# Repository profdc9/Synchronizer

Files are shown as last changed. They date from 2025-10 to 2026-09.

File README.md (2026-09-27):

# Synchronizer

Keep a mechanical pendulum clock on time by disciplining it to NTP or GPS —
**without modifying the clock in any way.**

The device sits behind the clock. Two coils reach through the back of the
case: one listens to the pendulum, the other nudges it. Nothing is glued to
the bob, nothing is drilled, nothing is tapped into the movement. Take the
device away and you have an ordinary pendulum clock again.

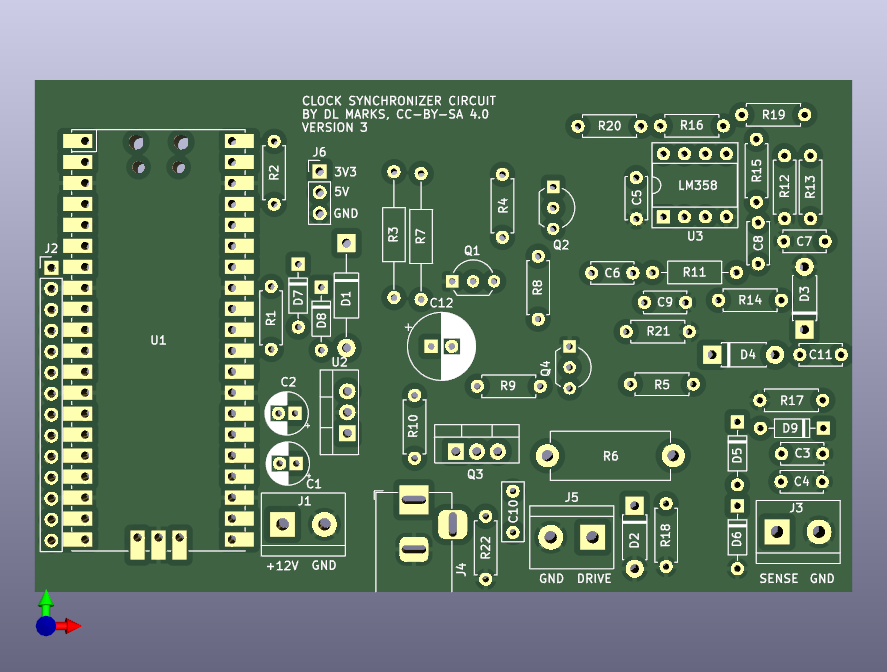
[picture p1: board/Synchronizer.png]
The board


## How it works

A pendulum clock keeps time by counting swings. If the pendulum runs a
little fast or slow — and they all do, with temperature, with the mainspring
unwinding, with the barometric pressure — the hands drift. The usual fix is
to adjust the rating nut and accept a few seconds a day.

This device measures the pendulum against an accurate reference and gives it
a very small push, at the right moment, to hold it on time.

### Sensing the pendulum

The **sense coil** is an air-cored coil of many turns. It sits behind the
case, near one end of the pendulum's travel, and forms a parallel resonant
tank with C3 (in parallel with C4, an optional trim position). The firmware
drives that tank at its resonant frequency with a square wave.

When the bob swings past, it changes the coil's inductance and loads it with
eddy-current loss. Either way the tank is pulled off resonance, its
impedance falls, and the voltage across it drops. An LM358 amplifies that,
and the result is read two ways: as the raw waveform, and through an
envelope detector that turns it into a slow bump. The bump is the bob going
past.

Arrival time is taken as the **midpoint between the two threshold
crossings**, not the peak. At the end of its travel the bob is nearly
stationary, so the bump is broad and its peak is poorly localised — but the
two flanks are steep and symmetric about the turning point.

### Nudging the pendulum

The **drive coil** is wound on a soft iron core and sits at the other end of
the swing. Energising it attracts the bob's steel backing. It can only pull,
never push, so correction is entirely a matter of *when*:

- pulse **just before** the bob arrives → it gets there sooner → **the clock
  advances**
- pulse **just after** it turns and starts back → it is held a moment
  longer → **the clock retards**

The pushes needed are tiny. On the development clock, correcting 11 s/day
works out to about **113 microseconds of retard per swing** — far too little
to deliver as a pulse every swing. So the firmware accumulates the demand
and spends it whole: one short pulse every few dozen swings.

### Keeping time

A Raspberry Pi Pico W runs the whole thing, and serves a web interface for
everything else — status, calibration, tuning. Setting one up needs no
serial terminal and no app: a board with no network raises its own access
point, and joining it opens the setup form. Afterwards it answers at
`synchronizer.local` and advertises itself over DNS-SD, so there is no IP
address to hunt for. The page carries a console that runs the same command
line as the serial port, and the same thing is reachable from `curl` for
scripting or remote debugging.

It gets the time over Wi-Fi by NTP, and keeps a model of UTC that NTP
corrects in both phase *and* rate —
the RP2040's crystal is only good to around 30 ppm, which is 2.6 s/day, a
sizeable fraction of the error being removed. A GPS receiver can be wired to
the expansion header later.

## The hardware

A single board, 99 × 62 mm, all through-hole parts. It is deliberately
**single-sided** — every track is on the bottom copper, with no vias and no
jumpers — so it can be milled at home if need be, though the boards in the
photo were commercially made.

### Connections

| | |
|---|---|
| **J1** | +12 V input, screw terminal |
| **J4** | +12 V input, barrel jack (wired in parallel with J1) |
| **J3** | Sense coil, screw terminal |
| **J5** | Drive coil, screw terminal |
| **J2** | 14-pin expansion header |

J2 carries GPIO5–GPIO15 with three grounds, for a GPS receiver or anything
else. GPIO12 and GPIO13 are UART0 TX/RX, on pins 10 and 11.

### Circuit blocks

**Power.** 12 V in, a 7805 down to 5 V, then a 1N5819 Schottky (D1) feeding
the Pico's VBUS and the LM358's supply. The diode is what lets you plug in
USB without back-feeding the regulator.

**Tank drive.** GPIO2 → Q1 (2N3904) → Q2 (2N3906), which injects into the
sense tank through R5 from the 12 V rail. A square wave at resonance.

**Amplifier.** Two inverting LM358 stages, both with 100 kΩ feedback,
biased to about 1.5 V so they run from a single supply. The op-amp is
socketed.

The first stage is fed from the tank through C6, only 100 pF, so its
reactance — roughly 80 kΩ at 20 kHz — dominates the 10 kΩ input resistor.
That makes the stage a gentle high-pass of about ×1.3 at 20 kHz rising with
frequency, rather than a flat ×10. C6 is a light tap on the tank rather than
a load on it, and it also adds its own 100 pF to the tank's capacitance
alongside C3. The second stage is AC-coupled through C8 and does run at
about ×10.

**Detectors.** The amplified waveform goes to ADC1 through R20. It also goes
through R19 and C11 into a clamp-and-rectify envelope detector (D3, D4) with
C9 and R21 setting the decay, and that goes to ADC0. D7 and D8 clamp both
ADC inputs to 3V3; D5, D6 and D9 clamp the tank input.

**Drive.** GPIO4 → Q4 (2N3904) → pulls the gate of Q3, an IRF9540N P-channel
MOSFET, whose source sits on +12 V. **GPIO4 high energises the coil.** The
current runs through R6, a 10 Ω power resistor. D2 (UF4007) is the flyback
clamp across the coil, and R22 with C10 snubs the switching node. R17 and
R18 are unpopulated positions for damping the coils if you need it.

**R6's job is damping the drive circuit's oscillations, not setting a
current limit by design** — size it to the coil actually wound rather than
assuming the populated value. A lower-resistance coil wants a smaller R6, and
in many cases R6 can be 0 Ω outright; a higher-resistance coil can tolerate,
and may need, more damping.

> **A word of caution about R6.** The coil's DC resistance depends on what
> you wind, and R6 is in series with it across 12 V. A pulse left on could
> put several watts into that resistor. The firmware bounds every pulse
> three independent ways — a hard ceiling on width, a watchdog timer that
> drops the pin regardless of what the rest of the code believes, and a
> token bucket capping the long-run duty cycle — and the pin is driven low
> before anything else initialises. Keep those limits in mind before
> widening the default pulse.

### Pin assignments

| Signal | Pico | Function |
|---|---|---|
| `/OSCIL` | GPIO2 | tank drive, square wave at resonance |
| `/PULSE` | GPIO4 | drive coil; **high = coil energised** |
| `/AMPLITUDE` | GPIO26 / ADC0 | envelope detector output |
| `/OSC_SIGNAL` | GPIO27 / ADC1 | amplified tank waveform |

## Physical setup

<table>
<tr>
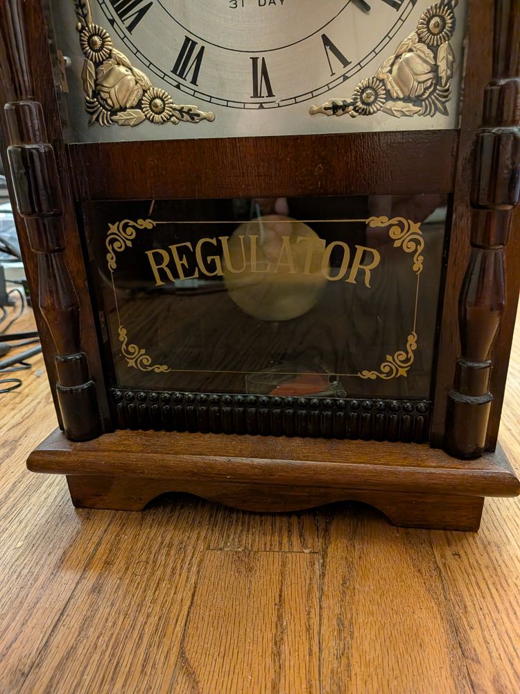
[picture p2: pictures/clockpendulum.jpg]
The development clock
<td width="50%"></td>
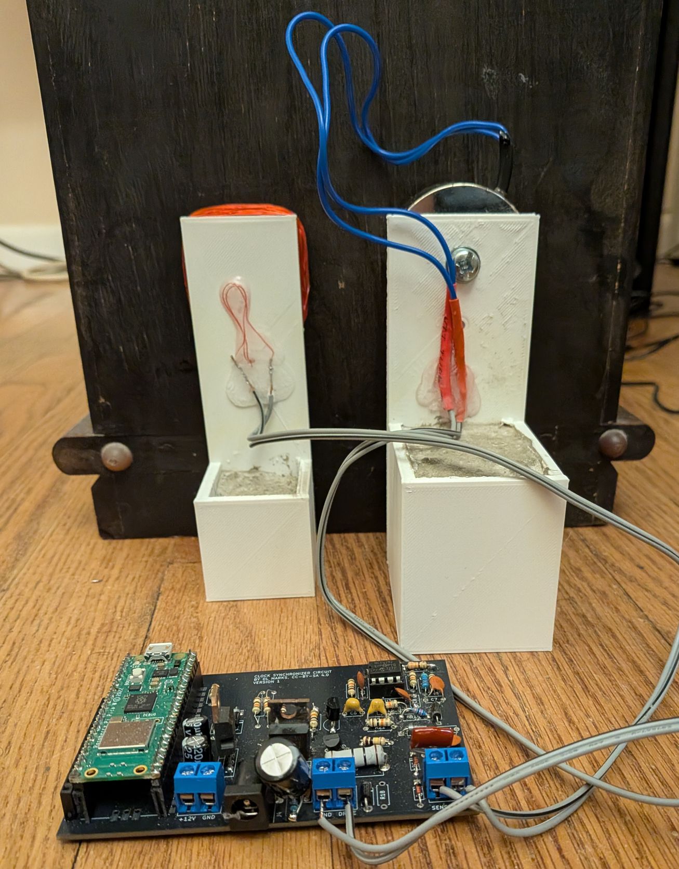
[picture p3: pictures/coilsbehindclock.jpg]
Both coil holders, wired to the board, standing behind the clock
<td width="50%"></td>
</tr>
<tr>
<td>The development clock — a 31-day mantel regulator. Neither coil touches
it; both stand free behind the case, reaching through the back wall.</td>
<td>The two coil holders assembled and wired to the board, placed at
opposite extremes of the pendulum's swing — the recommended default
geometry. Each stands on a 3D-printed platform with a ballast cup at its
base — filled here with cement — so it stays put on the shelf rather than
picking up the pendulum's own vibration.</td>
</tr>
<tr>
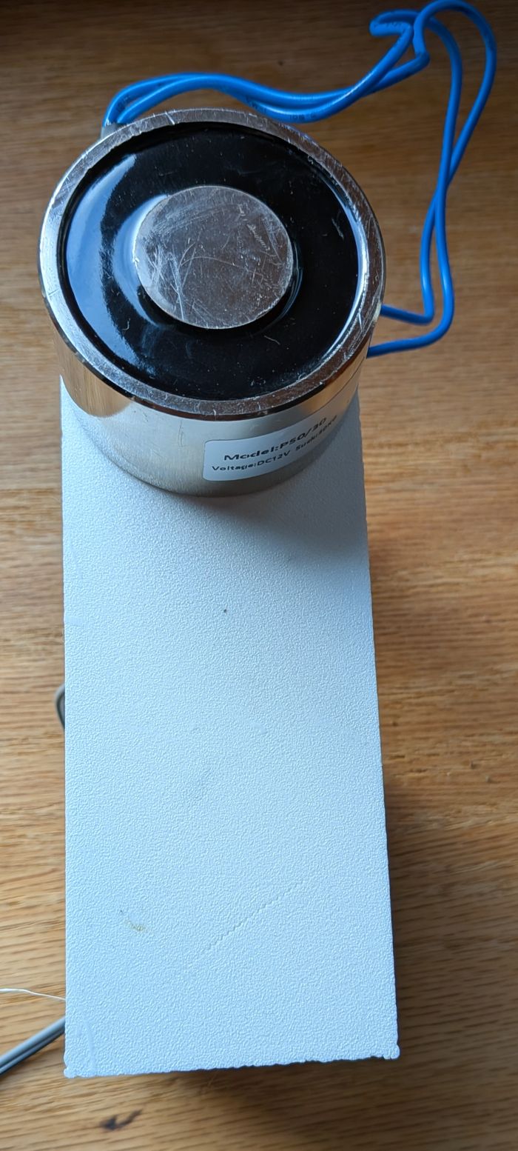
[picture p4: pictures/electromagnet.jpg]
The drive electromagnet on its mount
<td></td>
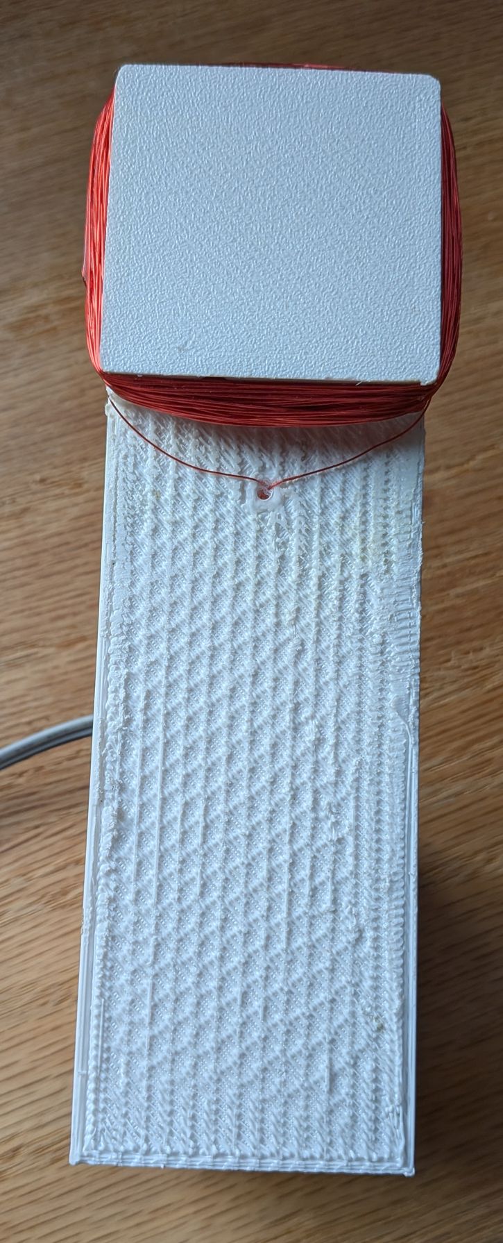
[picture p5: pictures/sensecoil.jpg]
The sense coil on its winding form
<td></td>
</tr>
<tr>
<td>The drive coil: a 50 mm × 35 mm, 500 N lifting electromagnet, 12 V at
about 250 mA, on its holder.</td>
<td>The sense coil, wound on its own form — the parallel resonant tank
described above.</td>
</tr>
</table>

Both holders are FreeCAD models, parametric in coil/magnet dimensions — see
`CAD/` below.

## The web interface

The device serves its own dashboard — no app, no cloud account, nothing to
install. These are from the clock above, running live.

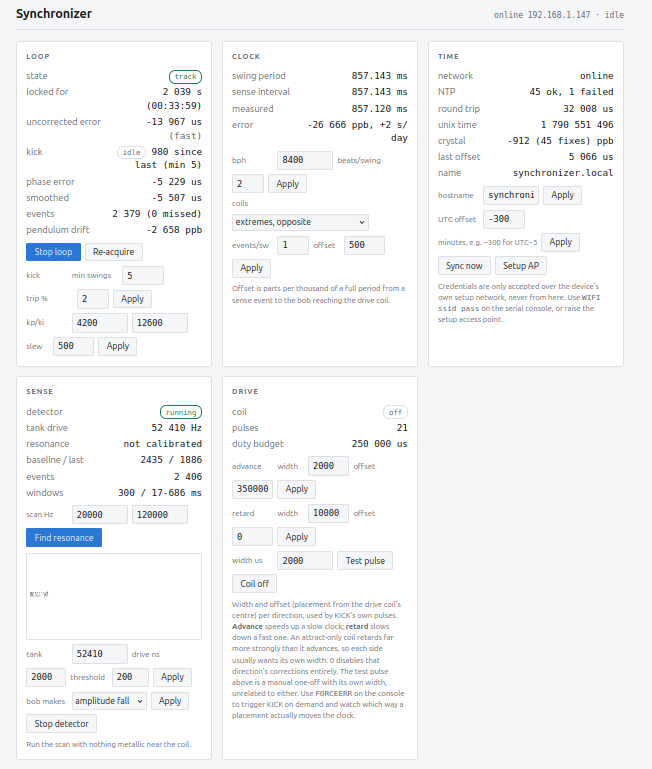
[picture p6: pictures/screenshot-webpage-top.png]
Loop, clock, time, sense and drive


At-a-glance status: the loop's lock state and uncorrected error, the clock's
measured swing rate, network and NTP health, the sense detector, and the
drive coil's per-direction pulse widths — all on one screen, live.

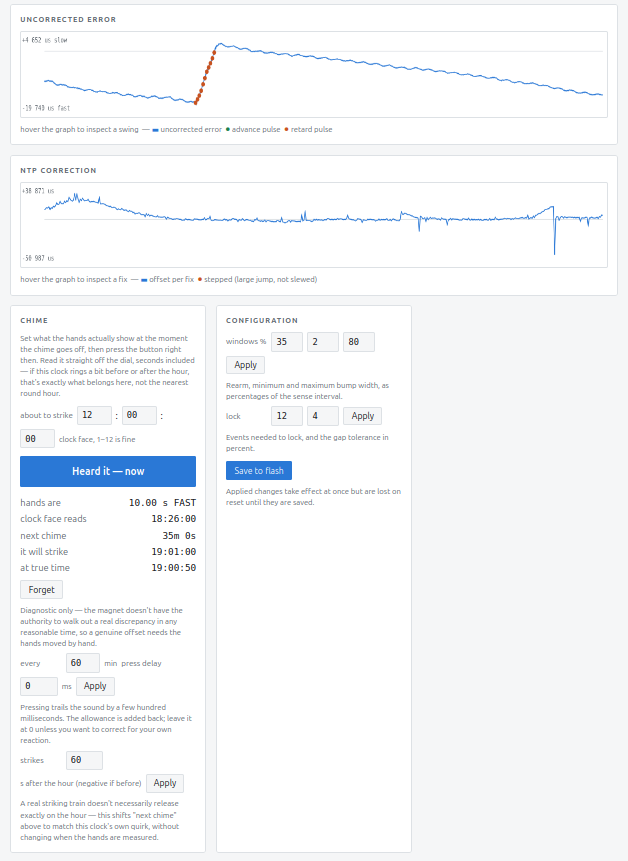
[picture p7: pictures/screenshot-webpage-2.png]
Error/correction history and the chime diagnostic


The uncorrected error over time, with advance and retard pulses marked where
they fired; the size of each NTP correction below it; and the chime
diagnostic showing what the hands should currently read.

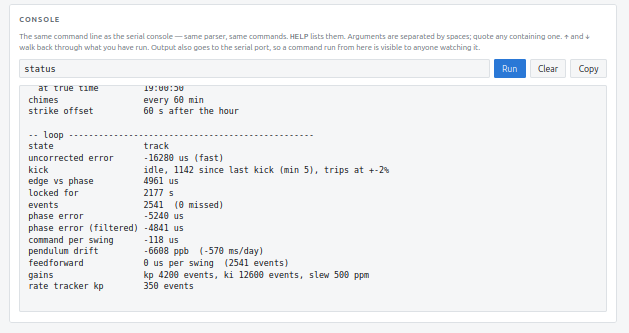
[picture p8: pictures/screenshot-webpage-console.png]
The console


The same command line as the serial port, in the browser — `STATUS` shown
here, but any command works, from `curl` or from this console.

## Repository layout

| | |
|---|---|
| `board/` | KiCad 7 project — schematic, PCB, gerbers, and a pcb2gcode setup for milling |
| `Code/synchronizer/` | Pico W firmware. See [its README](Code/synchronizer/README.md) for build and bring-up. |
| `CAD/` | FreeCAD models, parametric, plus their STLs. See [its README](CAD/README.md) for what each one is. |
| `Simulations/` | Qucs-S / ngspice models of the coil sensor and the coil pulser |

## Status

The board is built, the firmware runs the loop against the real clock shown
above, and it locks and holds it on time. Correction uses **KICK**: a
one-directional bang-bang scheme, no up-front gain measurement needed — it
fires a short pulse no more than once every few swings, only while the
error is on the side of zero that direction corrects, and stops once it
crosses back. An earlier design spent an accumulated phase error against a
measured "price per pulse" (`MEASURE`/`AUTH`); that path has been removed —
KICK needs no such calibration and has proven to be the simpler, working
approach.

Bring-up order, and the web interface, are in the
[firmware README](Code/synchronizer/README.md).

## Other clocks

Nothing in the firmware assumes a particular movement. Pendulum period,
escapement, gear ratio, coil placement and detector timing are all
configurable and stored in flash. The defaults describe the clock this was
developed against, and are only a starting point.

That clock is a 31-day wall clock about 40 cm tall. Measured from a
three-minute recording of its escapement:

- full swing period **0.857030 s** — nominally 6/7 s
- **8400 beats/hour**, 140 beats/min, **4200 full swings/hour**
- pendulum about **18.3 cm**
- runs roughly **11 s/day fast**
- **203 ms out of beat**, stably — the escapement releases at 0.678 of peak
  swing, where the bob still has 73% of its top speed, so it runs happily
  that way

Note that the bob only reaches each end of its travel once per full period,
so a coil at one extreme sees it 4200 times an hour, not 8400.

## Licence

The board carries **CC BY-SA 4.0** on its silkscreen, and the CAD models are
under the same licence; the full text is in
[`LICENSE-CC-BY-SA-4.0.txt`](LICENSE-CC-BY-SA-4.0.txt). The firmware sources
each carry a zlib-style permissive notice, and the full text is in
[`Code/synchronizer/LICENSE`](Code/synchronizer/LICENSE).

Daniel Marks

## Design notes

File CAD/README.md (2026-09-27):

# CAD

FreeCAD models for the coil and electromagnet holders, all designed by
Daniel Marks for this project. Each has a base cup for ballast (rocks, steel
shot, cement, ...) so the holder stands still on its own rather than picking
up the pendulum's vibration.

| File | Role |
|---|---|
| `WeightedCoilForm.FCStd` | The sense/drive coil holder, including the form the magnet wire is wound on. |
| `WeightedElectromagnetHolder.FCStd` | The platform that holds the drive electromagnet — in the photos, a 50 mm × 35 mm, 500 N lifting magnet, 12 V at about 250 mA. |
| `CoilBobbin.FCStd`, `CoilForm.FCStd`, `CoilFormWithPCBHolder.FCStd`, `CoilFormWithPCBHolder2.FCStd` | Earlier coil-form and PCB-holder designs. |

STLs are the printable exports of the corresponding model; `.FCBak` files are
FreeCAD's own backups and can be ignored.

## Licence

**CC BY-SA 4.0**, the same as the board — see
[`LICENSE-CC-BY-SA-4.0.txt`](../LICENSE-CC-BY-SA-4.0.txt) at the repository
root.

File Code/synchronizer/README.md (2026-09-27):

# Synchronizer firmware

Disciplines a pendulum clock to NTP time (GPS later), without modifying the
clock. Two coils sit behind the case on the pendulum's swing path, acting
through the back wall.

Nothing here assumes a particular movement. Pendulum period, escapement,
gear ratio, coil placement and detector timing are all configuration held in
flash. The defaults describe the 31-day clock it was developed against —
they are a starting point, not a specification.

Target: **Raspberry Pi Pico W**, SDK 2.x.

## Building

```sh
export PICO_SDK_PATH=/home/dmarks/pico/pico-sdk
cmake -S . -B build -G Ninja -DPICO_BOARD=pico_w -DCMAKE_BUILD_TYPE=RelWithDebInfo
ninja -C build
```

`build/synchronizer.uf2` is the image. The console is USB CDC at any baud
rate; the UART pins stay free for a GPS receiver on J2.

### Host tests

The part of the firmware most likely to be quietly wrong is the arithmetic
in `control.c`, and it is also the part hardest to check on the bench — a
swinging pendulum takes minutes per measurement and never repeats exactly.
So `test/` compiles `src/control.c` *unmodified* against stub headers and
feeds it synthetic swings with a known answer:

```sh
make -C test check
```

It checks that a persistently fast clock trips a retard and a persistently
slow one trips an advance, each releasing again once the pulses pull the
error back past zero; that a schedule slip forces a hold and the loop
reacquires afterward; and that a direction left at zero width trips but
never actually fires or releases. Run it after touching the loop; it takes
a second.

## What each piece does

| File | Role |
|---|---|
| `board.h` | Pin map, taken from the schematic. Nothing else hard-codes a pin. |
| `sense.c` | Drives the tank at resonance, samples the envelope at 1 kHz, and times each swing. |
| `drive.c` | Fires the impulse coil, with the safety limits described below. |
| `timebase.c` | A UTC model disciplined by NTP in both phase and rate. |
| `netclock.c` | WiFi association and the NTP client. |
| `control.c` | The phase-locked loop, and the sigma-delta that turns its demand into whole pulses. |
| `cli.c` | The serial command line. `HELP` lists everything. |
| `config.c` | Settings in the last flash sector, CRC-checked. |
| `tinycl.c` | Your command-line parser, reused unchanged. |

## Two things worth knowing before powering it up

**The drive coil can cook R6.** `GPIO4` high energises the coil from +12 V
through R6. Its job is damping the drive circuit's oscillations, not setting
a current limit by design, so its value has to be picked for the coil
actually wound: a lower-resistance coil wants a smaller R6, and in many
cases R6 can be 0 Ω outright, while a higher-resistance coil can tolerate,
and may need, more damping. Check the current schematic rather than
assuming a number here. Until the coil's DC resistance is measured and R6
sized for it, the current is unknown, and a stuck pulse could put several
watts into that resistor. So the firmware bounds every pulse three
independent ways: a ceiling of 100 ms on
any single pulse, a separate watchdog checked every 5 ms that forces the pin
low regardless of what the rest of the code believes, and a token bucket
that caps the long-run average duty at 2%. The pin is driven low
in `drive_init()` before anything else runs. Default pulse width is a timid
2 ms — widen it once you know what the coil draws.

**Nothing acts until you say so.** `control_enabled` defaults off, and even
once it is on, `PW`'s two widths gate whether either direction can ever
fire - 0 refuses that direction outright rather than falling back to a
guessed width. A fresh board will sit there sensing and telling you what it
sees; KICK needs no calibration step before it can act, just a nonzero
width for whichever direction(s) you want it to use.

## Bring-up, in order

**A firmware update can silently reset everything below.** The config sector
carries a magic number and a version; if a build changes the struct layout,
the device restores defaults on its next boot rather than reading a stale
layout — deliberately, since the alternative is misinterpreting bytes that
used to mean something else. That is the right call for tuning values, which
are guesses anyway, but it means `THRESH`, `WINDOWS`, `PW`, `PTIME`, `KICK`
and everything else below can vanish after a routine reflash with no warning
beyond `STATUS` quietly showing different numbers than you left it with. If a
clock that was working stops acquiring or measuring right after an update,
suspect this before suspecting the update's actual change — walk back through
the steps below rather than assuming the new code broke something.

**Run `RECREATE` before flashing new firmware.** It prints the sequence of
commands that would rebuild the current configuration from defaults —
`GEOMETRY`, `WINDOWS`, `PW`, `KICK`, and everything else that has been
tuned, `SAVE` included. It does not print `WIFI`; credentials are
deliberately left out of it. Save the output before a version bump wipes
it, and replaying it is a one-paste recovery instead of redoing bring-up
from scratch.

**0. Pick the tank components.** The inductive sense works best somewhere in
30-100 kHz. If you don't already know the sense coil's inductance, measure it
directly with an LCR meter, or estimate one you're winding yourself from
`L = mu_0 N^2 A / l` (turns squared, cross-sectional area, over coil length).
Either way, solve for C3 to land on a target frequency f in that band:

```
C = 1 / (4 pi^2 f^2 L)
```

A typical C3 lands somewhere between 1000 pF and 10000 pF for coils in the
few-mH range tuned into 30-100 kHz — worth a sanity check against the
calculation before ordering parts; a result far outside that band usually
means the wrong L or the wrong target frequency, not an unusual coil.

C3 is not the only capacitance across the tank, though: C6 taps the tank to
feed the amplifier — lightly enough that it does not load it down — but it
still adds its own value in parallel with C3, currently 30 pF on the
development board, so account for it (`C3 + C6`) when solving for a target
frequency, not C3 alone.

Pick the nearest standard capacitor value - an exact match is not needed,
because the next step measures the tank's *actual* resonance rather than
trusting the calculation. The development board's own sense coil is 2.5 mH on
a square 25x25 mm form, for reference.

**Use a film capacitor for C3, or a ceramic NP0/C0G type - not a typical
X7R.** X7R's capacitance shifts substantially with temperature and applied
voltage, which is exactly what a frequency-determining tank component cannot
tolerate; the tank frequency will drift and the whole detector chain rides on
that frequency staying put.

**1. Calibrate the tank.** With the sense coil on J3 and **nothing metallic
near it** — not the bob, not your hand, not a steel rule on the bench:

```
RESONANCE 20000 120000 Y
```

Two passes. A coarse scan locates the peak and gauges its width, then a fine
scan covers about three linewidths centred on it. The peak frequency comes
from a parabolic fit to the three points around the fine maximum, so it is
not limited to the step size; the half-power points come from linear
interpolation across the fine scan. The trailing `Y` prints the curve as a
bar chart.

It reports the peak, the −3 dB points, Q, and the two steepest flanks, then
adopts the peak. `SAVE` keeps it.

On a synthetic resonance the peak comes back within a few hertz — well under
one scan step — for Q anywhere from 12 to 120 and across the whole band. Q
itself is good to about 1% at moderate Q and drifts low by roughly 10% on a
very sharp tank, where the fine scan's step size limits how precisely the
flanks can be located.

Two things to watch for, both of which the command warns about:

- **Clipping.** If the envelope rails, the peak goes flat, the parabola
  slides off it and Q collapses. On the synthetic test a railed scan came
  back 302 Hz out with Q wrong by half. The command refuses to adopt a
  clipped result and leaves the drive where it was.
- **Harmonics.** The drive is a square wave, so a scan that passes through
  f0/3 and f0/5 will show smaller responses there too. The fundamental
  always wins, but do not be surprised by the subpeaks in the plot.

**Should you sit exactly on the peak?** Not necessarily. At the peak the
amplitude is stationary, so pure detuning by the bob only moves it to
*second* order. On the steepest flank — about 0.354 bandwidths either side of
centre, which is what the command prints — detuning moves it to first order,
which can be far more sensitive. Against that, the bob also *loads* the tank
through eddy-current loss, and that lowers the peak to first order even at
centre. Which mechanism dominates depends on your coil, your frequency and
how much brass versus steel the bob presents, so it is worth trying both:
run `RESONANCE`, note the peak amplitude, then hold the bob at its closest
approach and read `STATUS` at the peak and at each flank. Take whichever
gives the biggest swing.

`SWEEP 5000 60000 250` still prints a raw table if you want to look at the
whole band by hand, and `CAPTURE 500000 512` dumps the amplified waveform
from ADC1 so you can see what the LM358 is actually producing.

**2. Place the coil.** The tank peak found in step 1 is *not* where the
detector should sit. The bob's eddy losses drag the loaded resonance
downward, so the drive wants to be below the unloaded peak — on the
development clock, about 270 Hz below, worth 20% more signal. That optimum
moves whenever the coil moves, so let the board find it:

```
MODSCAN 0 0 0
```

It sweeps the drive, watches each frequency for longer than a full swing,
and reports how far the bob moves the envelope. **The peak-to-peak figure is
the entire signal budget** — maximise it by moving the coil, re-running after
each move. It leaves the drive on the winner.

**The recommended default geometry is opposite extremes**, and it is worth
starting there rather than exploring alternatives: sense coil at one extreme,
drive coil at the other. The photos in the top-level
[README](../../README.md#physical-setup) show the two coils placed exactly
this way. Place each coil about a quarter of the bob's own
diameter *beyond* where the bob's metal actually reaches at that extreme —
not centred on the point of deepest penetration. At the true turning point
the bob is nearly stationary, which is what produces a wide, poorly-localised
dip; offsetting the coil means it only sees the bob while it is still moving,
which gives a narrower, more sharply-timed crossing for the sense coil, and
lets the drive coil work through its *lateral fringe field* rather than a
direct, on-axis pull. "Bob diameter" here means the extent of the metal, not
any outer decorative dimension — the development clock's bob is a steel core
inside a brass envelope, so it is the full brass-covered diameter that
matters, since eddy-current sensing responds to any conductor and the brass
alone would still register even though it is not itself magnetic.

The drive coil benefits in particular from a design that leans into the
fringe field rather than fighting it: a commercial electromagnet meant for
attaching to metal, with a steel bolt glued to its own centre core so the
field extends past the coil's physical edge, measurably outperformed direct
placement attempts on the development clock — an evening of no measurable
authority at all became a clearly significant one purely from this change,
nothing else. Start here rather than rediscovering it by trial and error.

Geometry matters more than fine positioning. The bob's distance from a coil
at the swing *extreme* varies by twice the amplitude; at the *centre of
travel*, only by one amplitude. On the development clock that was 206 counts
against 75 — nearly 3:1 in favour of the extreme. Against that, the centre
gives two passes per period and the bob is moving fastest there. Try both;
`TRACE` tells you which you have, since a coil at the centre shows two
cycles per period and one at an extreme shows one.

Coil diameter is a genuine compromise: sensing depth grows with coil radius,
so too small cannot reach, while spatial resolution is also set by diameter,
so too large smears the pass into a slow sinusoid. Comparable to the standoff
is a good rule. Note that if the coil, the standoff and the bob's total
travel are all of similar size — 25 mm each on the development clock — the
bob never leaves the coil's field and the envelope is a smooth sinusoid at
the swing frequency rather than a sharp pass. That is geometry, not
misplacement, and it times perfectly well.

**3. Set the threshold.** `THRESH` is in ADC counts of envelope excursion
away from the tracked baseline, in the direction `DIR` selects. It decides
three things at once, which is why the extremes are both bad:

* whether a swing triggers at all,
* how wide the event is — a low threshold means crossing near the top of the
  dip and staying below it for most of the period,
* and the timing precision, since both edges are timed at exactly this level
  and precision is noise divided by the slope where they cross.

Run `WATCH Y` and look at the printed `peak`, which is the excursion the bob
actually produces. **Half of it is about right.** On the development clock,
peak ≈ 160 counts:

```
 THRESH  events  gap median   gap sd   width   misses
     25      17     857.3 ms     2.68   477 ms        2
     50      19     858.3        5.19   447          0
     90      19     856.6        2.24   324          0
    110      19     857.4        2.53   247          0
```

At 25 the events ran 477 ms wide against the 514 ms `max_event_pct` limit,
so one swing in ten was abandoned as stuck-high. At 90 — 56% of peak — no
misses and the lowest jitter. Too high is bad too: near the dip's floor the
slope flattens again and normal amplitude variation starts causing misses.

**If it stops acquiring entirely — not one swing in ten, every one of
them — the loop can look dead while the signal underneath is perfectly
healthy.** `STATUS` still shows `events` frozen at whatever it was, `chatter`
climbing steadily, and `baseline`/`last sample` both clearly alive and
moving. That combination — chatter increasing, `events` not — means events
are opening and never closing: every single one is running past
`max_event_pct` and getting abandoned as stuck-high before it can complete,
so none of them ever reach the width gate to be counted, rejected, or even
logged by `WATCH` (its echo only fires on events `sense.c` actually reports).
This is the same failure as the table above, just at 100% instead of 10% —
most often seen right after a reflash wiped `WINDOWS` back to its defaults
while the coil geometry underneath had since changed enough that the old
percentages no longer fit.

Diagnose it with `TRACE`, not by guessing new `WINDOWS` numbers: it plots the
raw envelope against time, bypassing the threshold/event state machine
entirely, so it shows the true dip regardless of whether detection is
currently working at all. Read the actual event width and gap straight off
the printed trace — where the excursion crosses `THRESH` on the way in to
where it recrosses `THRESH` minus `HYST` on the way out is the width; from
that crossing to the next event's crossing is the gap — and set:

```
WINDOWS <rearm%> <min%> <max%>
```

so `max%` clears the real width with margin and `rearm%` sits comfortably
*under* the real gap, not just under the nominal interval. A width that now
runs 60-70% of the period rather than the ~30-40% the defaults assume is not
a sign of a broken swing; it is what the recommended opposite-extremes-plus-
offset geometry in step 2 produces once the coil is close enough to have real
authority, and `WINDOWS` exists precisely so this is a one-line fix rather
than a rebuild.

`HYST` sets how far *below* the threshold the excursion must fall before the
event is declared over. It costs nothing in timing — both edges are still
timed at `THRESH` — and it stops ripple near the threshold from ending an
event early, which the width gate would then throw away entirely. 30% is a
good default; `STATUS` counts how often it saves a swing.

**A warning about the diagnostics.** `ENV`, `TRACE` and `MODSCAN` take the
ADC away from the detector while they run, so the detector is blind for
their duration and the loop will miss those swings. That is fine when you
are setting up, but do not leave one running and expect the loop to hold
lock, and do not trust `measured interval` until they have aged out.

**4. Get time.** 

```
WIFI myssid mypassword
SAVE
```

Credentials live in flash, not in the source. `STATUS` shows the association
and the NTP fix count. The timebase needs a few minutes and at least two
fixes before it starts correcting the RP2040 crystal's own error, which is
around 30 ppm — 2.6 s/day, a quarter of what we are trying to remove.

**5. Let the loop lock without acting.**

```
PW 0 0
CONTROL Y
```

With both pulse widths zero the loop tracks but never fires — KICK still
updates its active/idle state and `STATUS`'s `uncorrected error`, it just
never reaches `fire_for()`. Let it sit and watch `uncorrected error` walk at
the clock's natural rate — about 11 s/day fast, from the audio measurement —
before turning either direction on.

**6. Place the drive pulse.** `GEOMETRY events_per_swing drive_offset_ppt`
sets how long after a sense event the bob reaches the drive coil, as parts
per thousand of a full period - 500 for opposite extremes, the recommended
default. Treat that as a starting guess, not a fact: get a rough number by
timing the onboard LED (it blinks once per sense event) against the drive
coil by eye or stopwatch, convert to ppt, and set it with `GEOMETRY`.

`PTIME advance_us retard_us` nudges the placement by hand if that
rough centre needs adjusting. Both parameters are the same signed offset
from that centre - a given number means the same physical instant whether it
is stored as the advance placement or the retard one. What matters here is
the *sign*: a pulse fired on the wrong side of the bob's turning point
advances when it should retard, or the reverse - not the exact instant
within the half-period, since KICK's hysteresis works with whatever
authority a reasonably-placed pulse actually has, rather than needing that
authority measured in advance.

**Anything that physically disturbs the pendulum invalidates the rate
tracker**, not just the count of swings it has seen — touching the coil,
running `COILTEST`, adjusting the drive placement by hand. A disturbance
leaves a contaminated `rate_q` that only washes out over roughly `2 * RATEKP`
swings on its own; reissuing the same `RATEKP` value forces a clean restart
instead of waiting it out, and is worth doing on reflex after any physical
change.

**7. Turn a direction on and watch it run.**

```
PW 2000 2000
KICK 5 25
CONTROL Y
```

`PW advance_us retard_us` sets how wide each pulse is; 0 disables that
direction outright rather than falling back to a guessed width - a
direction the coil cannot usefully drive should simply not fire. `KICK
min_swings threshold_pct` sets how many swings must pass between pulses,
and how far past zero - as a percentage of one swing period - the
uncorrected error has to go before a direction is judged to need
correcting; it releases again as soon as the error crosses back past zero,
not out to the opposite threshold. There is no separate advance-mode or
retard-mode to pick - KICK reacts to whichever side the error is actually
on, and can run both directions at once if both widths are nonzero.

There is no bench measurement left to run first, and nothing to `SAVE` a
number from - watch it over real time instead. `STATUS`'s `uncorrected
error` should walk toward the threshold, trip a `kick`, and walk back
toward zero over the next few pulses; `locked for` counts how long that has
been happening without an interruption. `FORCEERR <us>` can confirm KICK
trips and releases in the right direction on demand, but it cannot hold an
artificial error in place long enough to judge a pulse width by - the real
measurement against NTP overwrites it within about one swing (see the doc
comment above `forceerr_cmd` in `cli.c`).

Leaving one width at zero is legitimate: the loop then corrects in one
direction only, which is all a clock that consistently gains (or
consistently loses) ever needs.

**A sensor artifact worth knowing about, if a bench-measurement tool is
ever rebuilt.** An earlier version of this loop *did* measure how many
nanoseconds of phase one pulse was worth, by firing pulses for a fixed
run and fitting the phase shift against the pendulum's own rate tracker.
That measurement turned up a real trap, and the trap outlives the tool
that found it:

A placement sweep that comes back with a smooth, coherent
placement-vs-kick curve - one sign across half the range, the other sign
across the rest, exactly the shape a real coil authority curve should
have - is not on its own evidence that the coil is doing anything. Run
the same sweep with the magnet moved away from the clock entirely; if a
similar curve still comes back, none of it is mechanical.

The suspected cause was that firing the drive coil disturbs `sense.c`'s
demod directly (supply sag, ground bounce, or coupling straight into the
tank coil), and since that demod is a delay-and-multiply phase detector
built on an I/Q accumulator that runs every ADC tick and is never reset, a
glitch on even a few samples shows up as a step that decays only over the
accumulator's own multi-swing time constant - indistinguishable from a
genuine kick. The fix tried was a guard window (`SENSEDEAD <us>`) that
stopped feeding samples into the accumulator for that long on either side
of every pulse.

It backfired. Measuring the same sweep at three guard widths -

```
SENSEDEAD 30000    ->  best-magnitude points around +-25000 ns/pulse
SENSEDEAD 10000    ->  the same shape, roughly a third the size
SENSEDEAD 0        ->  every point within about 1 sigma of zero, no shape at all
```

- showed the "fix" was the dominant source of the curve, scaling with the
guard width rather than shrinking it. The reason is structural, not specific
to this hardware: `dm_I`/`dm_Q` is a single-bin correlator estimating the
Fourier coefficient of the envelope at one cycle per swing, and removing a
fixed window from that correlation sum every cycle does not just lower its
gain — the product of two sinusoids splits into a DC term and a
second-harmonic term, and the second-harmonic part integrated over just the
missing window does not cancel. Its phase depends on *where* the window
sits, not on the true phase being measured, so blanking manufactures a bias
that tracks pulse placement directly — worse for a sharp, non-sinusoidal dip
(real harmonic content to feed the bias) than for a clean sinusoid, and
worse the wider the guard window. `SENSEDEAD` was removed rather than
defaulted to 0 and left in the config, since a knob whose only well-tested
setting is "off" is a trap for the next person tuning this board.

With no blanking, the magnet-away curve did not clearly survive above noise
either. So whatever the original electrical effect is, if it exists at all
it is smaller than that measurement could resolve, and it was very unlikely
to matter next to a much bigger problem: an attract-only coil at a
fringe-field placement measured *microseconds* of authority per pulse
against a clock that needs *~100 microseconds per swing* to correct - over
an order of magnitude short regardless of how cleanly it was measured. KICK
sidesteps the whole question by never needing that number in the first
place; this is preserved for whoever next builds a tool that does.

## The web interface

Once the board associates, it serves a page on port 80 at the address
`STATUS` prints. Everything the serial console does is there: live status,
the clock and coil geometry, the detector, the drive coil, the loop, and a
resonance scan that draws its own curve.

The serial CLI keeps working alongside it — and is also *on* the page: the
Console card runs the same command line, through the same parser and the
same command table. There is no second syntax to keep in step.

```sh
curl -s -X POST 'http://synchronizer.local/api/cli?cmd=STATUS'   # queue it
curl -s        'http://synchronizer.local/api/cli'               # read the output
```

The output comes back as plain text, so this is as pleasant from `curl` or a
script as it is from the browser. It works because the SDK's stdio layer
fans every `printf` out to all registered drivers: a capture driver sits
alongside USB and is switched on around the command, so **not one of the
firmware's `printf` calls had to change**. Output still reaches the serial
port at the same time, so a command run from a browser is visible to anyone
watching the wire.

Three things to know:

- **A command runs from the main loop, never in the HTTP handler.** The POST
  queues it and returns `202`; the page notices the result counter change in
  `/api/status` and fetches the output. `RESONANCE` alone blocks for three
  seconds, which an HTTP handler must not do.
- **Output is capped at about 4 kB** and marked `[output truncated]` past
  that. `CAPTURE 500000 256` and a full `SWEEP` both fit; larger dumps want
  the serial console.
- **`WIFI` and `APKEY` are refused here.** Credentials are deliberately
  settable only over the setup access point, and letting the console set
  them from your LAN would quietly undo that. They still work on the serial
  console.

The USB and web consoles share one `tinycl` command buffer, so typing on the
serial port at the exact moment a web command runs can garble one of them.
The result is a rejected command, not a wrong one.

Two things shape the design:

- **A resonance scan blocks for about three seconds**, which an HTTP handler
  must not do. Requesting one only queues it; `web_poll()` runs it from the
  main loop and the page watches the `job` field until it clears, then
  fetches the curve. The same applies to writing flash.
- **`http_dispatch()` runs in lwIP callback context**, so it never
  allocates, never touches the ADC or flash, and never blocks. Each of the
  three connection slots owns its own request and response buffers.

The page lives in flash as a C string. **Edit `web/page.html`, not
`src/webpage.c`**, and regenerate:

```sh
python3 web/genpage.py          # rewrite src/webpage.c
python3 web/genpage.py --check  # fail if it is stale
```

The generator refuses to write unless it can parse its own output back into
the exact bytes of the source, so a mistake in the escaping cannot reach the
firmware silently.

**There is no authentication.** Anyone who can reach the device on your
network can energise the drive coil. The pulse ceiling, the watchdog and the
duty bucket in `drive.c` bound what that can do to the hardware, but they
are not a security boundary — put this on a network you trust, or keep it to
the serial console.

## First-time setup, with no serial terminal

A board that has never been told a network raises **its own access point**
instead, and so does one that has failed to connect three times running —
which is what a mistyped password looks like from the inside. There is no
way to get locked out.

1. Join the Wi-Fi network **`Synchronizer-XXXX`** (the last two bytes of the
   board's unique ID). The key is **`synchronizer`**, changeable with
   `APKEY`.
2. Open any page. The device runs a DHCP server so your phone gets an
   address, and answers every DNS lookup with its own, so the captive-portal
   check fails and the setup form opens by itself. If it does not, go to
   **192.168.4.1**.
3. Pick your network from the list, or type it — scanning is best effort
   while the AP is up, so an empty list is normal and the text field always
   works.
4. Press Connect. Credentials are saved to flash, the AP drops and the
   device joins your network, where it answers at
   **http://synchronizer.local**.

`AP Y` raises the access point by hand, `AP N` drops it, and the main page
has a button for it too.

### Finding it afterwards

An mDNS responder answers for **`<hostname>.local`** — `synchronizer.local`
by default, changed with `HOSTNAME` or from the page — and advertises the
web interface as an **`_http._tcp`** service, so it also shows up in service
browsers (`avahi-browse -rt _http._tcp`, Safari's Bonjour list, Android's
NSD) without anyone knowing an address. It runs on the setup access point
too, so even provisioning works by name.

This is a convenience, not a guarantee. `.local` resolves reliably on macOS,
iOS, Windows 10 and later, and Linux with Avahi; **typing it into a browser
on Android is unreliable**, though service discovery from an app works
there. `STATUS` always prints the plain address, and so does your router's
client list.

Anything typed as a hostname is reduced to a legal DNS label — lower-cased,
with everything but letters, digits and interior hyphens dropped. The name
it settled on is echoed back, so `Papa's clock` becoming `papasclock` is
visible rather than silent.

### A note on ordering

Provisioning and raising or dropping the access point are **deferred to the
main loop**, not done in the HTTP handler that asked for them. Saving
credentials writes flash with interrupts masked, and tearing down an
interface from inside an lwIP callback would take away the very network the
reply still has to travel over. So the handler records the request, answers
the browser, and the change happens a moment later.

**Credentials are only accepted over that access point.** `net_provision()`
refuses otherwise, so nobody on your LAN can repoint the device at their own
network — they would have to be in radio range and raise the AP first.

The key on the setup AP is not much of a secret; it is written above. Its
job is to stop your home Wi-Fi password crossing an open link in the clear
while you type it in. Anyone within radio range who knows the default could
provision an unconfigured board, so change it with `APKEY` if that matters
where the clock lives.

## Setting it up for a different clock

Six commands cover everything clock-specific. Each one takes effect
immediately and `SAVE` keeps it; the config carries a magic number and a
version, so changing the structure in a future build restores defaults
rather than reading a stale layout.

```
BPH      8400 2     beats per hour, and beats per full swing
GEOMETRY 1 500      sense events per swing, drive coil offset
WINDOWS  35 2 60    detector windows, as % of the event interval
LOCK     12 4       events needed to lock, gap tolerance %
SAMPLE   1000       envelope sampling rate
TANK     55000      tank drive frequency (RESONANCE finds this)
```

**`BPH`** is the gear ratio. `beats_per_swing` is 2 for an anchor, deadbeat
or pin-pallet escapement — two pallets, one tooth released per half period.

**`GEOMETRY`** is where you put the coils, and it is the one most likely to
differ from this build:

| Sense coil | Drive coil | Command |
|---|---|---|
| at a swing extreme | at the other extreme | `GEOMETRY 1 500` |
| at a swing extreme | at the same extreme | `GEOMETRY 1 0` |
| at the swing centre | at an extreme | `GEOMETRY 2 250` |

A coil at an extreme sees the bob once per full period; one at the centre
sees it twice. The offset is how long after a sense event the bob reaches
the *drive* coil, in parts per thousand of a full period.

**`WINDOWS`** are percentages of the expected interval between sense events,
not fixed microseconds, so they follow the pendulum. On a 0.857 s clock the
defaults resolve to a 300 ms rearm and a bump between 17 ms and 514 ms; on a
seconds pendulum, to 700 ms and 40 ms–1.2 s. `STATUS` shows the resolved
values.

The event schedule is exact integer arithmetic in all of these. Checked on
the host across 8400/3600/7200/5400/14400/9000 bph, one and two events per
period, and a single-beat escapement: **zero nanoseconds of error over a
year** in every case.

## The clock this was developed against

Measured from a three-minute recording of the escapement on 2026-09-10:

- full swing period **0.857030 s**, nominal 6/7 s
- **8400 bph**, 140 beats/min, **4200 full swings/hour, 100,800/day**
- pendulum about **18.3 cm**
- runs **~11 s/day fast**
- **203 ms out of beat** — stable, and mechanically fine; the escapement
  releases at 0.678 of peak swing where the bob still has 73% of its top
  speed. Curable by shimming the case if you want, but the project does not
  need it.

100,800 swings/day is the gear-ratio constant, so the clock-face calibration
is now a confirmation step rather than a prerequisite. `BPH` changes it if
this movement turns out not to be standard.

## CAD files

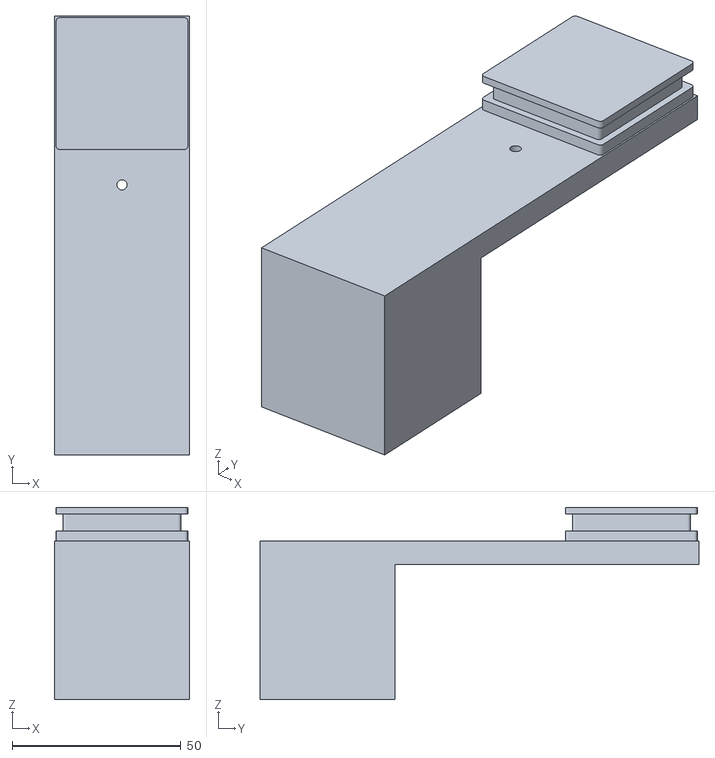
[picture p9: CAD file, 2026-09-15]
CAD/CoilFormStand-CoilFormTotal.stl
40.0 x 130.0 x 57.0

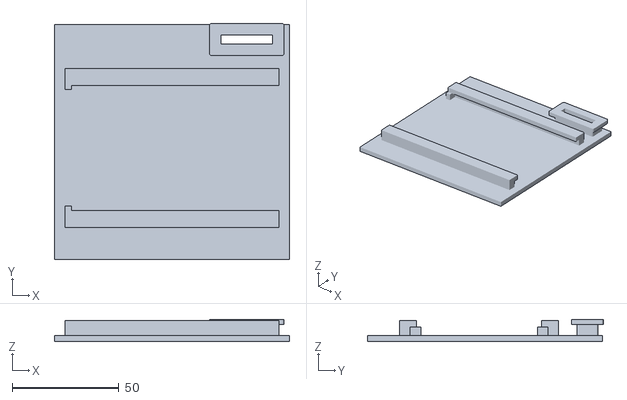
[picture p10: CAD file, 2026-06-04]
CAD/CoilFormWithPCBHolder-CoilFormTotal.stl
110.0 x 110.5 x 10.5

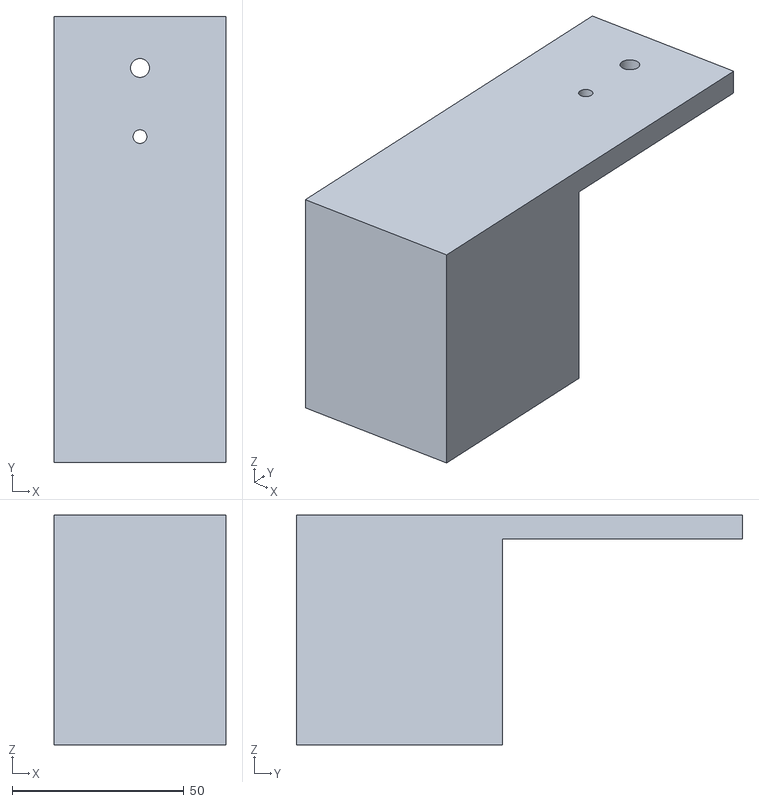
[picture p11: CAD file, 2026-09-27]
CAD/WeightedElectromagnetHolder-Electromagnet-Platform.stl
50.0 x 130.0 x 67.0

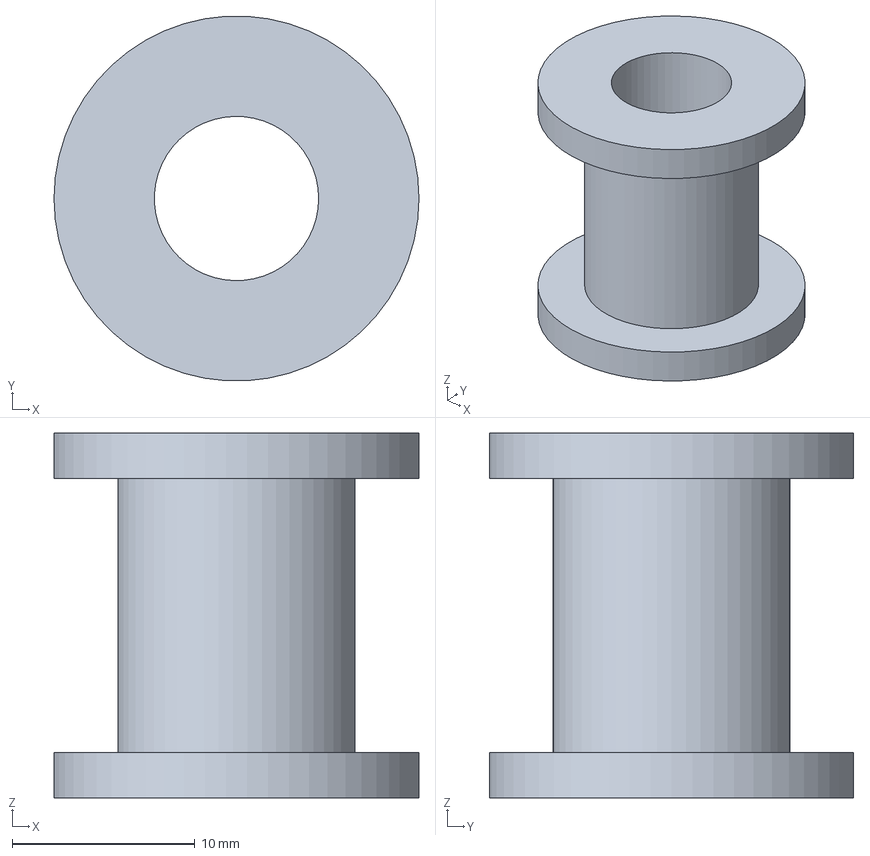
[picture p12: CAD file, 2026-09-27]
CAD/CoilBobbin.FCStd
20.0 x 20.0 x 20.0 mm

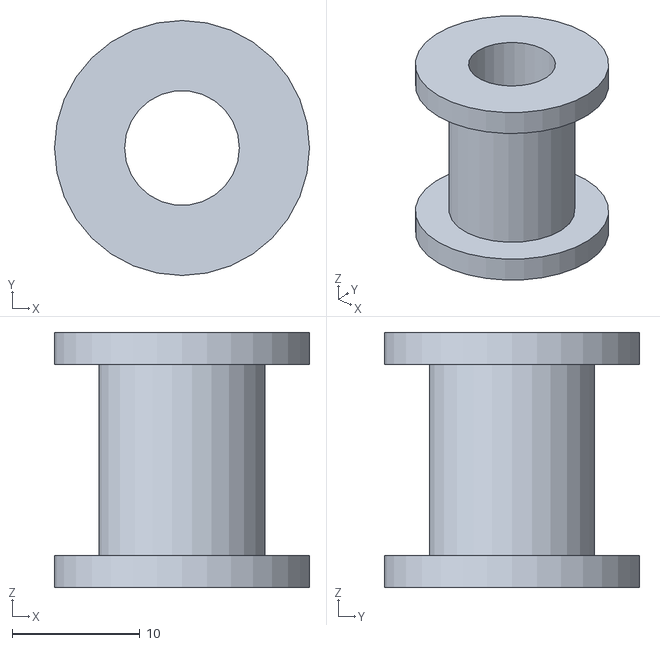
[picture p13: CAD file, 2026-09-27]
CAD/CoilBobbin-CoilBobbin.stl
20.0 x 20.0 x 20.0

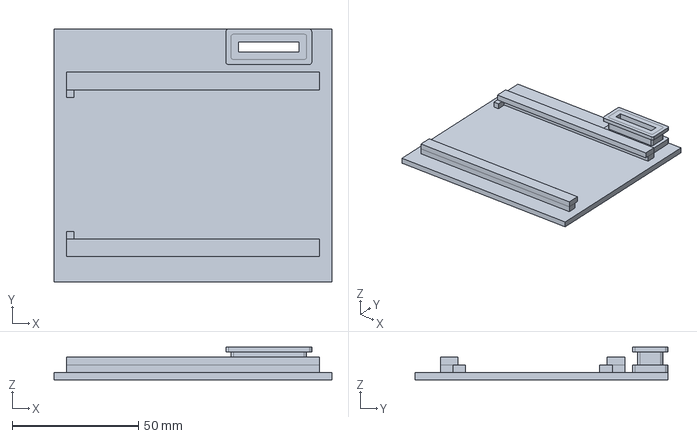
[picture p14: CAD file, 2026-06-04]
CAD/CoilFormWithPCBHolder.FCStd
110.0 x 100.0 x 13.0 mm

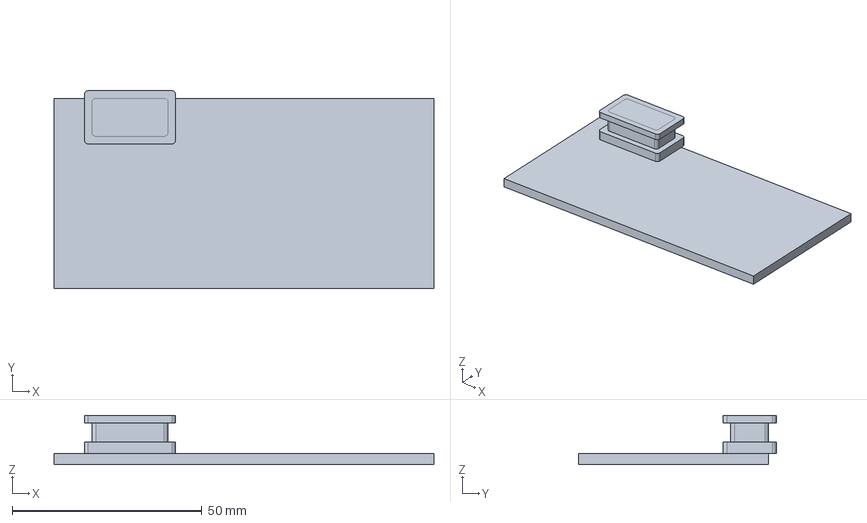
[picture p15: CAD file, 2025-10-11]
CAD/CoilForm.FCStd
100.0 x 52.0 x 13.0 mm

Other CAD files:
CAD/WeightedElectromagnetHolder.FCStd
CAD/WeightedCoilForm.FCStd
CAD/CoilFormWithPCBHolder2.FCStd

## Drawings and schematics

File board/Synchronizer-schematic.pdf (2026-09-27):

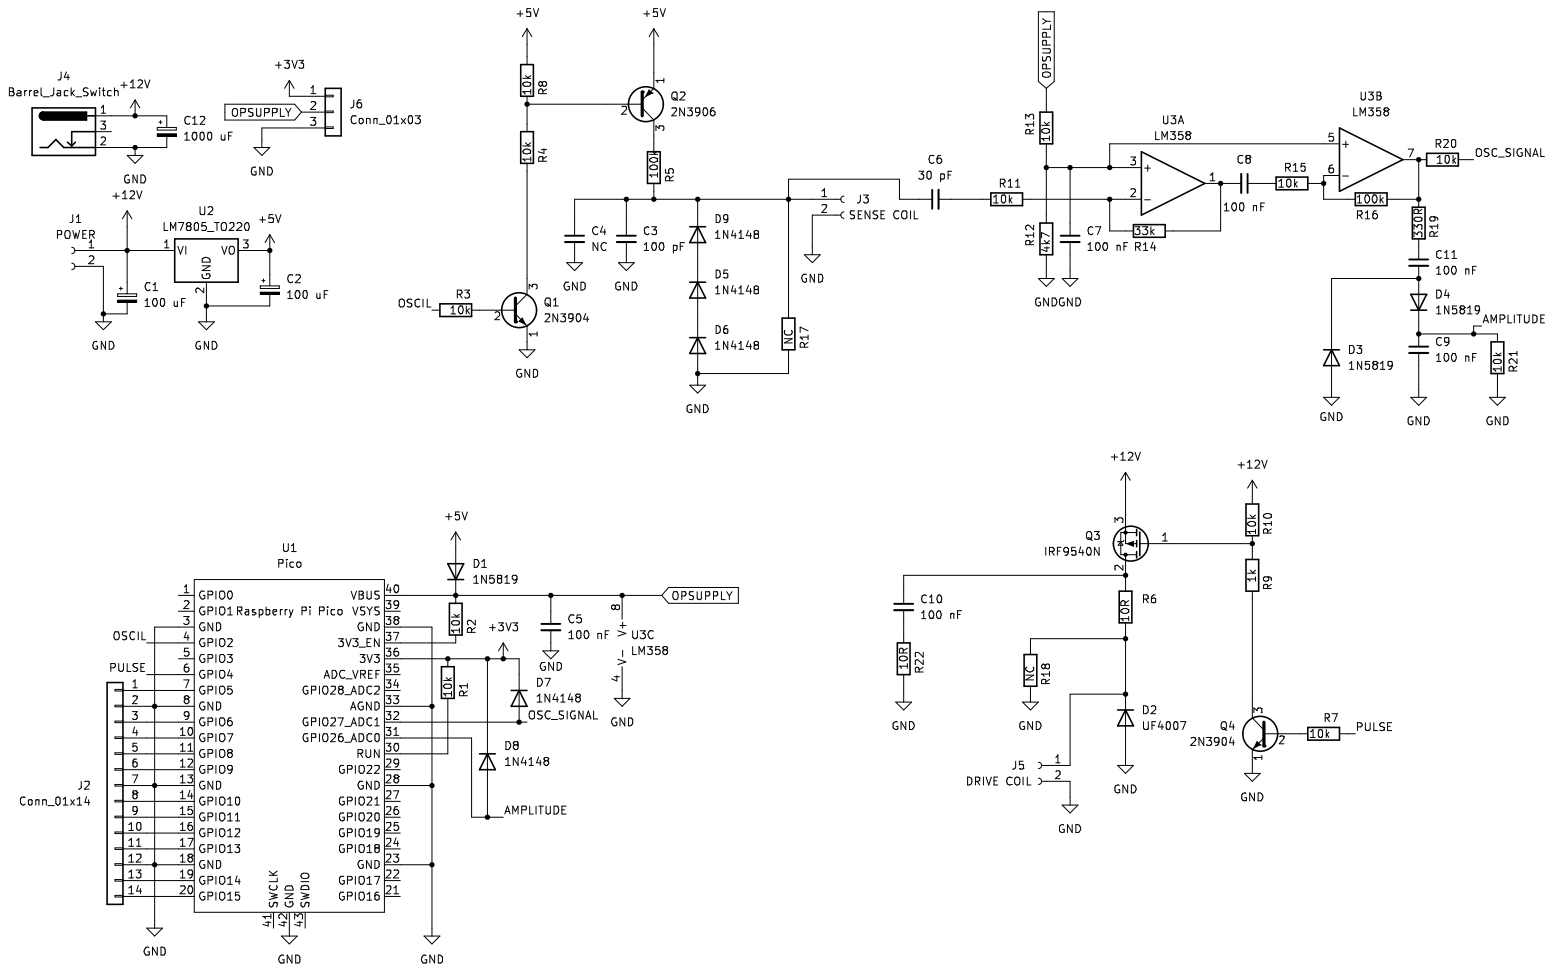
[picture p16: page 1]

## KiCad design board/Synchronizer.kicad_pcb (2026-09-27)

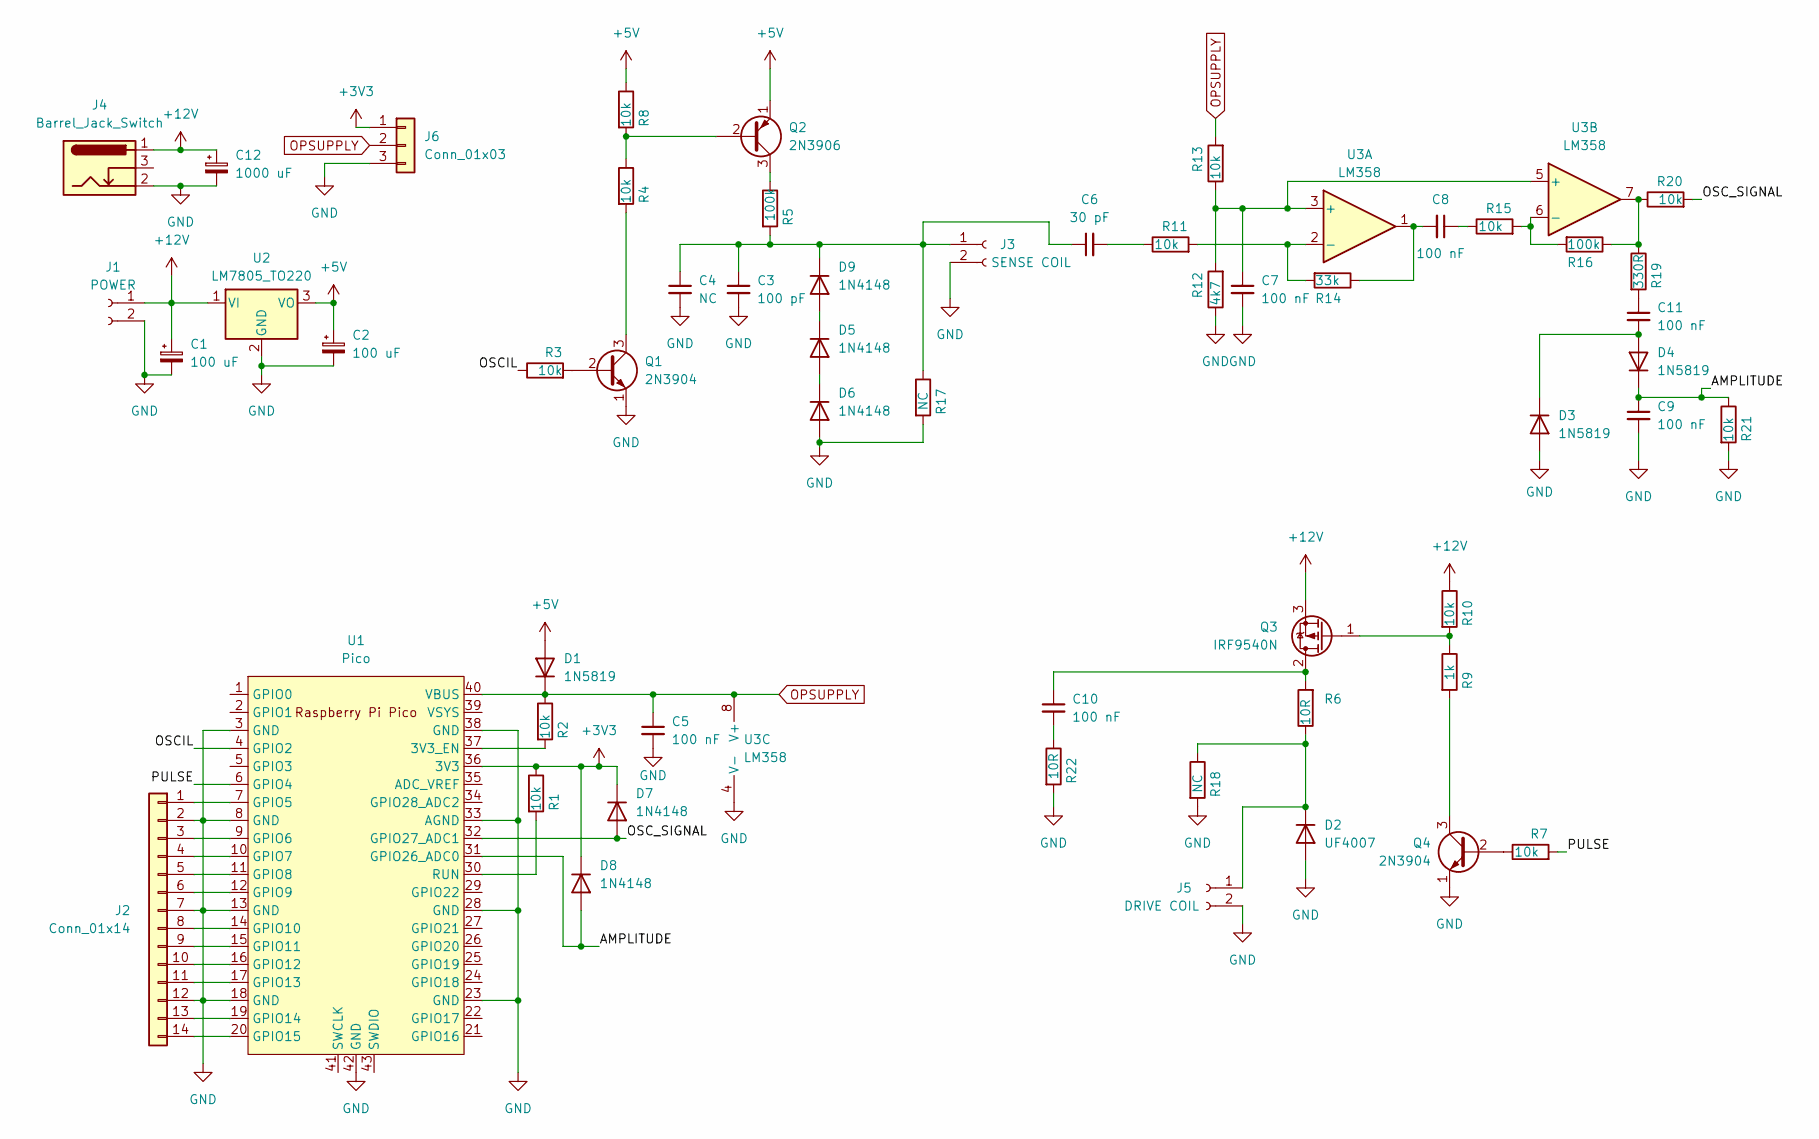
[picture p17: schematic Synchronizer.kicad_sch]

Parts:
C1, C2: 100 uF; CP_Radial_D5.0mm_P2.00mm
C3: 100 pF; C_Disc_D5.0mm_W2.5mm_P5.00mm
C4: NC; C_Disc_D5.0mm_W2.5mm_P5.00mm
C5, C7, C8, C9, C11: 100 nF; C_Disc_D5.0mm_W2.5mm_P5.00mm
C6: 30 pF; C_Disc_D5.0mm_W2.5mm_P5.00mm
C10: 100 nF; C_Rect_L7.0mm_W2.5mm_P5.00mm
C12: 1000 uF; CP_Radial_D8.0mm_P2.50mm
D1: 1N5819; D_DO-41_SOD81_P12.70mm_Horizontal
D2: UF4007; D_DO-41_SOD81_P7.62mm_Horizontal
D3, D4: 1N5819; D_DO-41_SOD81_P7.62mm_Horizontal
D5, D6, D7, D8, D9: 1N4148; D_DO-35_SOD27_P7.62mm_Horizontal
J1: POWER; TerminalBlock_bornier-2_P5.08mm
J2: Conn_01x14; PinHeader_1x14_P2.54mm_Vertical
J3: SENSE COIL; TerminalBlock_bornier-2_P5.08mm
J4: Barrel_Jack_Switch; BarrelJack_Horizontal
J5: DRIVE COIL; TerminalBlock_bornier-2_P5.08mm
J6: Conn_01x03; PinHeader_1x03_P2.54mm_Vertical
Q1, Q4: 2N3904; TO-92L_Inline_Wide
Q2: 2N3906; TO-92L_Inline_Wide
Q3: IRF9540N; TO-220-3_Vertical
R1, R2, R4, R8, R10, R13, R15, R20, R21: 10k; R_Axial_DIN0207_L6.3mm_D2.5mm_P7.62mm_Horizontal
R3, R7: 10k; R_Axial_DIN0207_L6.3mm_D2.5mm_P15.24mm_Horizontal
R5, R16: 100k; R_Axial_DIN0207_L6.3mm_D2.5mm_P7.62mm_Horizontal
R6: 10R; R_Axial_DIN0614_L14.3mm_D5.7mm_P15.24mm_Horizontal
R9: 1k; R_Axial_DIN0207_L6.3mm_D2.5mm_P7.62mm_Horizontal
R11: 10k; R_Axial_DIN0207_L6.3mm_D2.5mm_P10.16mm_Horizontal
R12: 4k7; R_Axial_DIN0207_L6.3mm_D2.5mm_P7.62mm_Horizontal
R14: 33k; R_Axial_DIN0207_L6.3mm_D2.5mm_P7.62mm_Horizontal
R17, R18: NC; R_Axial_DIN0207_L6.3mm_D2.5mm_P7.62mm_Horizontal
R19: 330R; R_Axial_DIN0207_L6.3mm_D2.5mm_P7.62mm_Horizontal
R22: 10R; R_Axial_DIN0207_L6.3mm_D2.5mm_P7.62mm_Horizontal
U1: Pico; RPi_Pico_SMD_TH
U2: LM7805_TO220; TO-220-3_Vertical
U3: LM358; DIP-8_W7.62mm_Socket

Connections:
+3V3: D7.1 (K), D8.1 (K), J6.1, R1.1, U1.36 (3V3)
+5V: C2.1, D1.2 (A), Q2.1 (E), R8.1, U2.3 (VO)
+12V: C1.1, C12.1, J1.1, J4.1, Q3.3 (S), R10.1, U2.1 (VI)
/AMPLITUDE: C9.1, D4.1 (K), D8.2 (A), R21.1, U1.31 (GPIO26_ADC0)
/OSCIL: R3.1, U1.4 (GPIO2)
/OSC_SIGNAL: D7.2 (A), R20.2, U1.32 (GPIO27_ADC1)
/PULSE: R7.2, U1.6 (GPIO4)
GND: C1.2, C2.2, C3.2, C4.2, C5.2, C7.2, C9.2, C12.2, D2.2 (A), D3.2 (A), D6.2 (A), J1.2, J2.2, J2.7, J2.12, J3.2, J4.2, J5.2, J6.3, Q1.1 (E), Q4.1 (E), R12.1, R17.2, R18.2, R21.2, R22.2, U1.3 (GND), U1.8 (GND), U1.13 (GND), U1.18 (GND), U1.23 (GND), U1.28 (GND), U1.33 (AGND), U1.38 (GND), U1.42 (GND), U2.2 (GND), U3.4 (V-)
unnamed: C6.2, R11.1
unnamed: C8.1, R15.1
unnamed: C8.2, R14.1, U3.1
unnamed: C10.2, R22.1
unnamed: C11.1, R19.2
unnamed: D2.1 (K), J5.1, R6.1, R18.1
unnamed: C11.2, D3.1 (K), D4.2 (A)
unnamed: D5.2 (A), D6.1 (K)
unnamed: D5.1 (K), D9.2 (A)
unnamed: C3.1, C4.1, C6.1, D9.1 (K), J3.1, R5.2, R17.1
unnamed: J2.1, U1.7 (GPIO5)
unnamed: J2.3, U1.9 (GPIO6)
unnamed: J2.4, U1.10 (GPIO7)
unnamed: J2.5, U1.11 (GPIO8)
unnamed: J2.6, U1.12 (GPIO9)
unnamed: J2.8, U1.14 (GPIO10)
unnamed: J2.9, U1.15 (GPIO11)
unnamed: J2.10, U1.16 (GPIO12)
unnamed: J2.11, U1.17 (GPIO13)
unnamed: J2.13, U1.19 (GPIO14)
unnamed: J2.14, U1.20 (GPIO15)
unnamed: Q1.2 (B), R3.2
unnamed: Q1.3 (C), R4.2
unnamed: Q2.2 (B), R4.1, R8.2
unnamed: Q2.3 (C), R5.1
unnamed: C10.1, Q3.2 (D), R6.2
unnamed: Q3.1 (G), R9.1, R10.2
unnamed: Q4.2 (B), R7.1
unnamed: Q4.3 (C), R9.2
unnamed: R16.1, R19.1, R20.1, U3.7
unnamed: R2.2, U1.37 (3V3_EN)
unnamed: R1.2, U1.30 (RUN)
unnamed: C7.1, R12.2, R13.1, U3.3 (+), U3.5 (+)
unnamed: R11.2, R14.2, U3.2 (-)
unnamed: R15.2, R16.2, U3.6 (-)
OPSUPPLY: C5.1, D1.1 (K), J6.2, R2.1, R13.2, U1.40 (VBUS), U3.8 (V+)

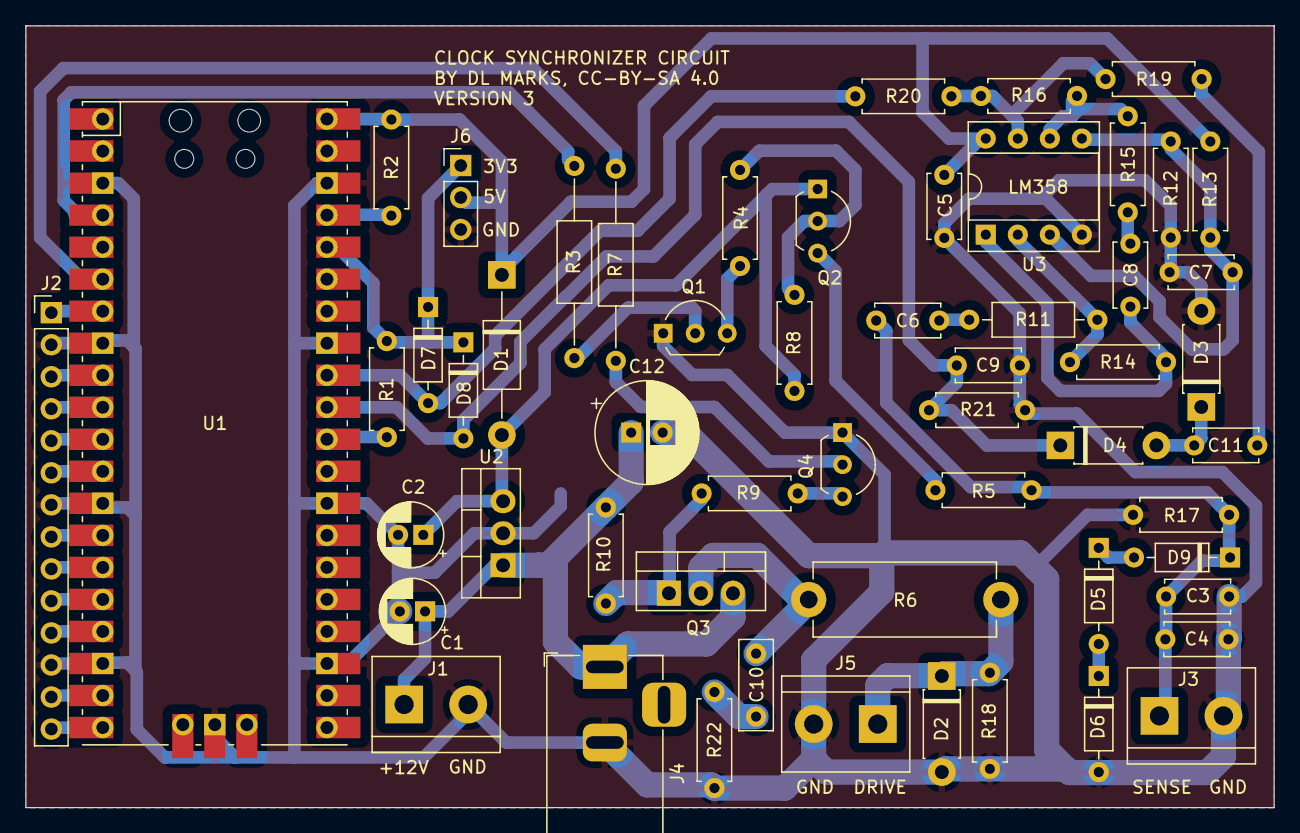
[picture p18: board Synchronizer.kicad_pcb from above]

Board: 2 copper layers, 99.0 x 62.0 mm, 56 parts (0 on the bottom side), 44 nets.

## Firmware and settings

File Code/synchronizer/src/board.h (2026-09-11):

/* board.h - pin map and fixed constants for the Synchronizer board

   Every pin here is taken from board/Synchronizer.kicad_sch (net names in
   brackets).  Do not change these without changing the PCB.
*/

/*
   Copyright (c) 2026 Daniel Marks

  This software is provided 'as-is', without any express or implied
  warranty. In no event will the authors be held liable for any damages
  arising from the use of this software.

  Permission is granted to anyone to use this software for any purpose,
  including commercial applications, and to alter it and redistribute it
  freely, subject to the following restrictions:

  1. The origin of this software must not be misrepresented; you must not
   claim that you wrote the original software. If you use this software
   in a product, an acknowledgment in the product documentation would be
   appreciated but is not required.
  2. Altered source versions must be plainly marked as such, and must not be
   misrepresented as being the original software.
  3. This notice may not be removed or altered from any source distribution.
*/

#ifndef _BOARD_H
#define _BOARD_H

#ifdef __cplusplus
extern "C" {
#endif

/* --- sense side ------------------------------------------------------- */

/* [/OSCIL] GPIO2 -> R3 -> Q1 (2N3904) -> R4 -> Q2 (2N3906) -> R5 -> tank.
   Driving this square wave at the tank's resonance excites the parallel
   LC formed by the sense coil (J3) and C3 || C4. */
#define GPIO_OSCIL          2

/* [/AMPLITUDE] GPIO26 / ADC0.  Envelope detector (R19, C11, D3, D4, R21, C9)
   fed from the LM358 second stage.  This is the slow control-path signal. */
#define GPIO_AMPLITUDE      26
#define ADC_CH_AMPLITUDE    0

/* [/OSC_SIGNAL] GPIO27 / ADC1.  The amplified tank waveform itself, before
   envelope detection.  Diagnostics only - it needs a fast capture. */
#define GPIO_OSC_SIGNAL     27
#define ADC_CH_OSC_SIGNAL   1

/* --- drive side ------------------------------------------------------- */

/* [/PULSE] GPIO4 -> R7 -> Q4 (2N3904) -> R9 -> gate of Q3 (IRF9540N, P-ch).
   Q4 on pulls the gate toward ground, VGS = -12 V, the FET conducts.
   So: GPIO4 HIGH energises the drive coil on J5.  It must idle LOW.

   The coil current runs through R6 (10R).  With an unknown coil resistance
   that resistor can be asked to dissipate several watts, so every pulse is
   bounded in both width and duty cycle - see drive.h. */
#define GPIO_PULSE          4

/* --- expansion -------------------------------------------------------- */

/* J2 carries GPIO5..GPIO15 for the GPS receiver that may be added later.
   GPIO12/GPIO13 are UART0 TX/RX (J2 pins 10 and 11). */
#define GPIO_GPS_TX         12
#define GPIO_GPS_RX         13
#define GPS_UART            uart0

/* --- the clock ---------------------------------------------------------

   DEFAULTS ONLY.  Nothing in this firmware may assume a particular
   movement: pendulum period, escapement, bob material and coil placement
   all vary from clock to clock, and every one of them is configurable and
   stored in flash.  These values seed a fresh configuration and describe
   the clock the firmware was developed against, nothing more.

   That clock: measured from a three-minute recording of the escapement on
   2026-09-10, the pattern repeats every 0.857030 s, which is 8400 beats
   per hour within the measurement error - 4200 full swings/hour,
   100800/day.

   beats_per_period is 2 for an anchor, deadbeat or pin-pallet escapement:
   two pallets, one tooth released per half period. */
#define DEFAULT_BEATS_PER_HOUR   8400u
#define DEFAULT_BEATS_PER_PERIOD 2u

#ifdef __cplusplus
}
#endif

#endif /* _BOARD_H */

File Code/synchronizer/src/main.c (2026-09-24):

/* main.c - Synchronizer: discipline a pendulum clock to NTP time */

/*
   Copyright (c) 2026 Daniel Marks

  This software is provided 'as-is', without any express or implied
  warranty. In no event will the authors be held liable for any damages
  arising from the use of this software.

  Permission is granted to anyone to use this software for any purpose,
  including commercial applications, and to alter it and redistribute it
  freely, subject to the following restrictions:

  1. The origin of this software must not be misrepresented; you must not
   claim that you wrote the original software. If you use this software
   in a product, an acknowledgment in the product documentation would be
   appreciated but is not required.
  2. Altered source versions must be plainly marked as such, and must not be
   misrepresented as being the original software.
  3. This notice may not be removed or altered from any source distribution.
*/

#include <stdio.h>
#include "pico/stdlib.h"
#include "pico/cyw43_arch.h"
#include "board.h"
#include "config.h"
#include "sense.h"
#include "drive.h"
#include "timebase.h"
#include "netclock.h"
#include "control.h"
#include "cli.h"
#include "hardware/watchdog.h"
#include "httpd.h"
#include "webui.h"
#include "conout.h"

/* Slow heartbeat on the Pico W's onboard LED: one blink per detected swing
   while events are arriving, steady off when they are not. */
static void led_task(void)
{
  static uint64_t shown;
  static bool     lit;
  uint64_t last;

  if (net_status() == NET_FAILED) return;   /* no cyw43, no LED */
  last = sense_last_event_us();

  if (last != shown && last != 0ull)
  {
    shown = last;
    lit   = true;
    cyw43_arch_gpio_put(CYW43_WL_GPIO_LED_PIN, 1);
  }
  else if (lit && (time_us_64() - shown) > 60000ull)
  {
    lit = false;
    cyw43_arch_gpio_put(CYW43_WL_GPIO_LED_PIN, 0);
  }
}

/* Every stage prints before it runs, so a hang names itself.  With the
   watchdog rebooting after eight seconds, a stage that never returns shows
   up as the same trail repeating - which is far easier to read than a board
   that has simply gone quiet. */
#define STEP(name) do { printf("[boot] " name "\r\n"); stdio_flush(); } while (0)

int main(void)
{
  stdio_init_all();
  conout_init();

  if (watchdog_caused_reboot())
    printf("\r\n[boot] *** previous boot hung - watchdog reset ***\r\n");
  printf("\r\n[boot] synchronizer starting\r\n");
  stdio_flush();

  watchdog_enable(8000, 1);

  /* Before anything else: the coil must be off and stay off.  Nothing
     downstream is allowed to assume a sane pin state. */
  STEP("drive");    drive_init();
  STEP("config");   config_load();
  STEP("timebase"); tb_init(cfg.xtal_ppb);
  STEP("sense");    sense_init();
  STEP("control");  control_init();
  STEP("net");      net_init();
  STEP("web");      web_init();
  STEP("cli");      cli_init();
  printf("[boot] running\r\n");

  for (;;)
  {
    watchdog_update();
    conout_poll();
    cli_poll();
    control_poll();
    net_poll();
    led_task();

    /* The listener can only be created once lwIP has an interface, and
       long jobs queued by the browser run here rather than inside an
       HTTP callback. */
    if (!httpd_running() && (net_status() == NET_ONLINE || net_in_ap()))
      httpd_init(80);
    web_poll();

    /* threadsafe_background does the lwIP work in the background, but this
       keeps the driver serviced on builds that use polling instead. */
    cyw43_arch_poll();
  }
  return 0;
}

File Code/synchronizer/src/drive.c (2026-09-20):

/* drive.c */

/*
   Copyright (c) 2026 Daniel Marks

  This software is provided 'as-is', without any express or implied
  warranty. In no event will the authors be held liable for any damages
  arising from the use of this software.

  Permission is granted to anyone to use this software for any purpose,
  including commercial applications, and to alter it and redistribute it
  freely, subject to the following restrictions:

  1. The origin of this software must not be misrepresented; you must not
   claim that you wrote the original software. If you use this software
   in a product, an acknowledgment in the product documentation would be
   appreciated but is not required.
  2. Altered source versions must be plainly marked as such, and must not be
   misrepresented as being the original software.
  3. This notice may not be removed or altered from any source distribution.
*/

#include "pico/stdlib.h"
#include "hardware/gpio.h"
#include "board.h"
#include "config.h"
#include "drive.h"
#include "sense.h"

static volatile bool     pin_on;
static volatile uint64_t on_since_us;
static volatile uint32_t pulses, refused;
static volatile uint64_t last_pulse_us;

static volatile uint32_t bucket_us;      /* remaining duty allowance */
static volatile uint64_t bucket_ts_us;

static alarm_id_t        off_alarm = -1;
static alarm_id_t        on_alarm  = -1;
static repeating_timer_t guard_timer;

/* What the watchdog in guard_cb() currently treats as "too long".  Always
   DRIVE_MAX_PULSE_US except for the few seconds a coil test is actually
   running, so the watchdog still backstops that pulse too instead of
   tripping partway through it. */
static volatile uint32_t guard_ceiling_us = DRIVE_MAX_PULSE_US;
static volatile bool     coil_test_used;
static volatile bool     coil_test_active;  /* sense is blinded for this, not a real pulse */

static void coil_off(void)
{
  gpio_put(GPIO_PULSE, 0);
  pin_on = false;
}

static void coil_on(void)
{
  on_since_us = time_us_64();
  pin_on = true;
  gpio_put(GPIO_PULSE, 1);
}

static void bucket_refill(void)
{
  uint64_t now = time_us_64();
  uint64_t dt  = now - bucket_ts_us;
  uint64_t add;

  if (dt < 1000u) return;
  add = (dt * DRIVE_DUTY_PPM) / 1000000u;
  bucket_ts_us = now;
  if (add == 0u) return;
  if (bucket_us + add > DRIVE_BUCKET_US) bucket_us = DRIVE_BUCKET_US;
  else bucket_us += (uint32_t)add;
}

static int64_t off_cb(alarm_id_t id, void *user)
{
  (void)id; (void)user;
  coil_off();
  off_alarm = -1;
  return 0;
}

/* Independent of the alarm above: if the pin has been high too long for any
   reason at all, drop it. */
static bool guard_cb(repeating_timer_t *rt)
{
  (void)rt;
  bucket_refill();
  if (pin_on && (time_us_64() - on_since_us) > (uint64_t)(guard_ceiling_us + 5000u))
    coil_off();
  return true;
}

static bool start_pulse(uint32_t width_us)
{
  if (width_us == 0u || width_us > DRIVE_MAX_PULSE_US) { refused++; return false; }

  bucket_refill();
  if (bucket_us < width_us) { refused++; return false; }
  bucket_us -= width_us;

  guard_ceiling_us = DRIVE_MAX_PULSE_US;   /* an ordinary pulse always gets the ordinary ceiling */
  if (off_alarm > 0) { cancel_alarm(off_alarm); off_alarm = -1; }
  coil_on();
  off_alarm = add_alarm_in_us(width_us, off_cb, NULL, true);
  if (off_alarm < 0) { coil_off(); refused++; return false; }   /* never start what cannot be stopped */

  pulses++;
  last_pulse_us = on_since_us;
  return true;
}

static int64_t on_cb(alarm_id_t id, void *user)
{
  (void)id;
  on_alarm = -1;
  start_pulse((uint32_t)(uintptr_t)user);
  return 0;
}

void drive_init(void)
{
  gpio_init(GPIO_PULSE);
  gpio_put(GPIO_PULSE, 0);
  gpio_set_dir(GPIO_PULSE, GPIO_OUT);
  gpio_put(GPIO_PULSE, 0);
  pin_on = false;

  pulses = refused = 0;
  last_pulse_us = 0;
  bucket_us    = DRIVE_BUCKET_US;
  bucket_ts_us = time_us_64();
  guard_ceiling_us = DRIVE_MAX_PULSE_US;
  coil_test_used   = false;
  coil_test_active = false;

  add_repeating_timer_ms(-5, guard_cb, NULL, &guard_timer);
}

bool drive_pulse(uint32_t width_us) { return start_pulse(width_us); }

bool drive_pulse_at(uint64_t when_us, uint32_t width_us)
{
  uint64_t now = time_us_64();
  int64_t  dt  = (int64_t)(when_us - now);

  if (width_us == 0u || width_us > DRIVE_MAX_PULSE_US) { refused++; return false; }
  if (dt < 0) { refused++; return false; }
  /* Was a flat 2 s "two swings", which is less than ONE swing on a
     seconds pendulum.  Follow the configured period instead. */
  {
    int64_t horizon = (int64_t)(cfg_period_ns() / 1000ull) * 2ll;
    if (horizon < 100000ll) horizon = 100000ll;
    if (dt > horizon) { refused++; return false; }
  }

  if (on_alarm > 0) { cancel_alarm(on_alarm); on_alarm = -1; }
  if (dt < 200ll) return start_pulse(width_us);

  on_alarm = add_alarm_in_us((uint64_t)dt, on_cb, (void *)(uintptr_t)width_us, true);
  if (on_alarm < 0) { refused++; return false; }
  return true;
}

static int64_t coil_test_off_cb(alarm_id_t id, void *user)
{
  (void)id; (void)user;
  coil_off();
  guard_ceiling_us = DRIVE_MAX_PULSE_US;   /* hand the watchdog back its normal ceiling */
  off_alarm = -1;
  if (coil_test_active) { sense_diag_end(); coil_test_active = false; }
  return 0;
}
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

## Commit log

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2026-09-11 New Pico W firmware for pendulum clock discipline
    Fresh project at Code/synchronizer, targeting a Pico W against SDK 2.x.
    The earlier tree is left alone at Code/old-project; tinycl is reused from
    it unchanged.
    The clock's numbers come from the three-minute escapement recording:
    8400 bph, 4200 full swings/hour, 100800/day, running about 11 s/day fast.
    That gear ratio is the constant the clock-face calibration was meant to
    find, so it is a default here rather than something to be discovered.
    board.h pin map from the schematic; the only place a pin appears.
    /PULSE is GPIO4, correcting the old firmware's GPIO3.
    sense.c drives the tank at resonance, samples the envelop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
    [board.h, drive.c]
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2026-09-11 Make the clock's rate and coil placement configuration, not assumptions
    The firmware had five constants that quietly assumed the movement it was
    developed on. Each worked fine here and would have failed silently on
    someone else's clock, so all five are now fields in the flash config, which
    already restores defaults on a magic or version mismatch. Version goes to 3,
    so existing boards re-default rather than reading a stale layout.
    beats_per_period was BEATS_PER_SWING, fixed at 2.
    events_per_period was implicit: the sense coil had to sit at a swing
    extreme and report once per full period. A coil at
    the centre of the swing reports twice.
    d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
    [board.h, drive.c, sense.c]
2026-09-11 Add a project README, and the web interface
    The top-level README explains what the device does and how the board works:
    the sensing and drive principles, the circuit blocks with their part
    references, the connectors and pin assignments, what is in each directory,
    and the measured figures for the development clock - marked as a test case
    rather than a specification.
    One correction it forced: the first LM358 stage is not a flat x10. C6 is
    only 100 pF, so its reactance - about 80 kohm at 20 kHz - dominates the
    10 kohm input resistor, making the stage a gentle high-pass of roughly x1.3
    at 20 kHz that rises with frequency. C6 is a light tap on the tank rather
    than a load on it, and contributes i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
    [main.c, sense.c, webui.c]
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2026-09-11 Run console commands from the web page, and from curl
    Your suggestion, and it is the better shape: one mechanism instead of a
    telnet server, no second protocol, no IAC negotiation, and it serves a
    browser and a script equally.
    The part worth knowing is that none of the firmware's printf calls had to
    change. The SDK's stdio layer already fans output out to every registered
    driver, so a capture driver now sits alongside USB and is switched on around
    a command. Output still reaches the serial port at the same time, so a
    command issued from a browser is visible to anyone watching the wire.
    Injection goes in through tinycl's own getchar hook, so the web console and
    the serial console share one p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
    [webui.c]
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2026-09-11 Fix the lwIP timeout pool exhaustion that halted the firmware
    The board associated with the setup AP and then did nothing: no DHCP, no
    console, no keystrokes, and PuTTY hanging on close. All of it was one fault.
    lwIP sizes MEMP_NUM_SYS_TIMEOUT from a formula that does not count mDNS at
    all, and mdns.c only says "increase it by one". One was not enough - the
    responder runs on two interfaces here, the station and the setup access
    point, and its probe and announce sequence schedules several timeouts of its
    own. lwIP does not degrade when that pool runs dry, it panics:
    *** PANIC *** sys_timeout: timeout != NULL, pool MEMP_SYS_TIMEOUT is empty
    which halts the firmware outright. The access po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
    [main.c, sense.c]
2026-09-11 Connect asynchronously, turn off Wi-Fi power save, escape JSON strings
    Three faults between "the phone showed the setup form" and a device that
    actually works on the network. All three found on hardware.
    The console died the moment Connect was pressed because
    cyw43_arch_wifi_connect_timeout_ms blocks the main loop for up to twenty
    seconds and the watchdog fires at eight. Joining a network rebooted the
    board, which tried again, and looped. The blocking call was wrong here
    anyway - twenty seconds with no console, no web server and no discipline
    loop is not acceptable on a device meant to be minding a clock. Connecting
    is now asynchronous with the link status polled from net_poll, so
    NET_CONNE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
    [webui.c]
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2026-09-15 Default the tank to 55 kHz and widen the resonance scan to match
    The sense coil measures 2.5 mH, which against C3 plus a 3.3 nF C4 puts the
    tank near 54.6 kHz. The old 20 kHz default predated knowing either value
    and implied a 633 mH coil, which is not a thing anyone would wind; the scan
    range that went with it, 2..80 kHz, no longer brackets where the tank
    actually sits.
    Defaults are now 55 kHz with a 20..120 kHz scan. The low end deliberately
    starts above f0/3: the tank is driven with a square wave, so scanning below
    a third of the fundamental invites the third harmonic to hit resonance and
    raise a spurious peak.
    Widening the span without adding points would have made the coarse pass
    sp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
    [sense.c, webui.c]
2026-09-15 Add a drive-level control for the sense tank
    The tank was driven at a fixed 50% duty, which assumes the coil someone
    wound presents an amplitude the amplifier can survive. On the development
    coil it does not: 2.755 mH against 3.4 nF is sqrt(L/C) = 900 ohms, and fed
    through R5 the tank node carries volts, so the envelope sat on the ADC rail
    across the whole band and the scan reported a clipped constant instead of
    an impedance curve.
    DRIVE sets the duty in PER MILLE, 0..500. Percent was tried first and is
    too coarse - one percent was still five times more than this tank could
    take. The fundamental scales as sin(pi*duty), so the useful range is
    compressed into the bottom of the scale and th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
    [sense.c, webui.c]
2026-09-15 Set the tank drive as a pulse width, not a duty
    A duty is a moving pulse width: the PWM wrap changes with frequency, so a
    fixed per-mille duty makes the pulse narrow as the scan climbs. That is
    harmless until the width crosses what the 2N3904/2N3906 pair will pass -
    56 ns works on this board, 48 ns does nothing at all - and then an
    ordinary rounding step becomes a cliff.
    It showed up as a scan that was a clean Lorentzian up to 53537 Hz and the
    bare floor above it. Nothing wrong with the tank: at 53537 the level
    rounded to 7 counts, at 53616 it rounded to 6, and the drive simply
    stopped partway up the sweep.
    DRIVE now takes nanoseconds. The width is constant across a scan by
    construction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
    [sense.c, webui.c]
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2026-09-15 Take a trimmed mean of the envelope burst, not a plain one
    Two different noises sit on the envelope and they want different treatment.
    The residual carrier ripple is periodic, so averaging cancels it. But an
    impulse is not additive - a 52 kHz switcher on this board and a radio a few
    inches away - and a single outlier drags a mean by its whole amplitude over
    N, however many samples are in the burst.
    Sorting the sixteen conversions and dropping four from each end keeps both
    properties: the middle eight still average the ripple down, and up to four
    spikes at either end are discarded outright. ENV_TRIM of 7 would make it
    the plain median of sixteen, 0 the arithmetic mean; 4 is the useful midd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
    [sense.c]
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2026-09-15 Make a diagnostic that blinds the detector say so
    RESONANCE, SWEEP, CAPTURE, ENV, TRACE and MODSCAN all take the ADC away
    from the detector while they run, and until now they did it silently. The
    loop went on believing it was tracking, read the silence as a phase
    excursion, and the interval spanning the blind stretch reached the rate
    statistics as one enormously slow swing.
    That cost real time on the bench twice today. Using ENV as a delay while
    waiting for the loop to settle produced a pendulum drift of 156 million ppb
    and a measured interval half a second long, and the erratic numbers looked
    like a detector fault rather than the measurement disturbing what it
    measured.
    Every ADC borrow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
    [sense.c]
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2026-09-15 Make the detector's filtering configurable, before the board leaves the desk
    env_oversample, env_trim and baseline_shift were compile-time, which was
    fine while the board lived next to a USB cable. It goes back to its own
    room shortly, and there is no OTA - deliberately, since OTA without A/B
    partitions, rollback and a signed image is a way to brick something across
    the house. So changing one of these means fetching the board.
    The trim is the one that will want changing. A drive coil pulsing a few
    inches from the sense coil is a far larger impulsive source than anything
    on this board today, and trimming is precisely the defence against
    impulses: tonight it was worth 4x where a plain mean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
    [sense.c]
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2026-09-15 MEASURE rides the rate tracker; PTIMESCAN ranks by sign
    Two defects that made the authority measurement untrustworthy, both worth
    fixing while the board is still on the desk.
    MEASURE read four single samples of the phase error and differenced them.
    Per-swing timing noise is 2.27 ms and the thing being measured is tens of
    microseconds, so the same measurement came back +185 us and then -41 us per
    pulse - which is what sent me fitting it by hand on the host.
    It now uses the pendulum rate tracker, which is what the tracker was worth
    building for beyond feedforward. Through a measurement the NCO stops
    learning and stops being pulled: it free-runs on the rate it had already
    learned, a flywheel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
    [board.h]
2026-09-15 CAD: weighted coil form and electromagnet holder
    The weighted versions of both mounts, plus the stand's exported mesh. A
    coil that has to sit against the outside of a case with nothing clamped or
    screwed to the clock has to hold its own position, so the mass is part of
    the design rather than an afterthought - the whole project is void if the
    sensor needs fixing to the movement.
    Also stop tracking FreeCAD's .FCBak files. It writes a fresh one on every
    save, so they churn the history for nothing; the .FCStd beside each one is
    the source and git is the backup. The three already committed are dropped
    from the index and left on disk.
    Clau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
    [CoilFormStand-CoilFormTotal.stl, WeightedCoilForm.FCStd, WeightedElectromagnetHolder-Electromagnet-Platform.stl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]
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2026-09-16 Fix detector baseline lockup and duplicated web console output
    sense.c: sample_cb's "stuck high" abandon path and sense_diag_end()
    (called after ENV/TRACE/etc.) both reseeded baseline_q to whatever
    the ADC happened to read at that instant. On the wide, deep envelope
    this clock's Schottky-diode detector now produces, that instant is
    often mid-dip rather than at rest, and since baseline_q only updates
    while !in_event, a bad seed makes it chase the waveform's mean instead
    of the peak - shrinking the apparent excursion until it can no longer
    cross THRESH at all. That's a self-sustaining lockup: escaping it
    needs exactly the detection it prevents. Found live: after a TRACE
    call ended mid-slope, t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
    [sense.c]
2026-09-16 Fix baseline reacquire at its root, and add a one-shot coil-pull test
    The lockup fixed earlier this session (reseeding baseline_q from a
    single instantaneous ADC sample, which can land mid-dip and leave the
    EMA chasing the waveform's mean instead of its peak) turned out to
    have a third, more fundamental instance: cold boot itself. baseline_q
    starts at 0, and the old lazy-init seeded it from whatever the very
    first sample happened to be - the same coin flip, just on every single
    boot rather than only after a diagnostic. That explains why some
    reboots this session "just worked" and one came up completely dead.
    Fixed at the root instead of patching another call site: baseline
    reacquisition (co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
    [drive.c, sense.c]
2026-09-16 Fix the real cause of the recurring baseline lockup: a live EMA bias
    The reacquire fixes earlier this session addressed bad SEEDS - cold
    boot, post-diagnostic, an abandoned event - but the lockup kept
    recurring during ordinary, undisturbed tracking with none of those
    involved. Caught live with per-tick polling: baseline was still
    visibly updating tick to tick (ruling out a stuck in_event), while
    chatter/events/rejected were all frozen. Computing dev at the observed
    trough against the observed baseline came out under THRESH - the
    baseline had settled at roughly the midpoint of the oscillation, not
    the peak.
    The mechanism: the EMA update ran on every !in_event tick, which
    includes not just ge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
    [sense.c]
2026-09-16 Raise the correction-pulse ceiling to 100 ms
    The coil measured 48R; through R6 (10R) that's ~0.21A - about 0.4W in
    R6 and ~2.1W in the coil, well within what COILTEST already proved
    both can shed continuously for 5 whole seconds. No thermal reason left
    to cap a single pulse at 50 ms.
    Widening DRIVE_MAX_PULSE_US to 100000 exposed a real bug: cfg.pulse_us
    was a uint16_t (max 65535), so any width above that would have
    silently wrapped instead of clamping to the new ceiling. Widened it to
    uint32_t, matching pulse_advance_us/pulse_retard_us's own already-wider
    handling, and bumped CONFIG_VERSION since the layout changed.
    Claude-Session: ht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
    [webui.c]
2026-09-17 MEASURE authority: fix silent pulse-refusal bug, add a lock-in phase detector
    fire_for() discarded drive_pulse_at()'s success/failure. A pulse refused
    by the duty budget still counted toward meas_fired and still deducted
    credit, so MEASURE's "per pulse" figure was silently divided by more
    pulses than were ever delivered, and the real correction-spending path
    believed it had paid for corrections the pendulum never received. It now
    returns that result and every caller checks it.
    That alone didn't explain repeated MEASURE runs disagreeing by more than
    their own quoted error bars - five real 60-pulse runs gave a reduced
    chi-square of 2.36 against their stated uncertainty, confirming the
    inconsi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
    [sense.c]
2026-09-17 Discipline loop: UTC-locked demod reference, type-2 NTP loop, pure accumulate-and-correct
    Three changes to how the clock actually gets disciplined, following on
    from tonight's delay-and-multiply phase detector:
    sense.c's demod reference now tracks true UTC via tb_ppb() instead of the
    raw local crystal. ADC ticks are driven directly by the RP2040's crystal
    (good to perhaps 30 ppm), so dm_n raw ticks are a fixed physical duration
    regardless of what that duration is worth in true UTC ns. Harmless for
    any one swing, but a real, compounding bias if these readings are ever
    summed over a long span - which is exactly what the next two changes do,
    so it has to be fixed at the source rather than co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
    [sense.c]
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2026-09-20 drive: fix COILTEST cutting short every time the loop was tracking
    drive_coil_test() set the wide guard_ceiling_us before calling
    sense_diag_begin(), but that calls control_blind() -> drive_all_off(),
    which unconditionally resets guard_ceiling_us back to the ordinary
    DRIVE_MAX_PULSE_US. The wide ceiling was silently clobbered before the
    pin ever turned on, so the independent watchdog cut the test at ~105ms
    instead of the requested duration whenever the loop was running. Move
    the assignment after sense_diag_begin(), immediately before coil_on().
    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
    [drive.c]
2026-09-20 control: symmetric signed pulse placement, safer scheduling margins
    Widen pulse_advance_us/pulse_retard_us from uint16_t to int32_t and
    put both on the same formula (when = centre + offset), so a given
    number means the same physical instant whether it is stored as the
    advance placement or the retard one, and either can reach a full half
    period from centre in either direction - the old fixed-sign, +-65535
    design could not reach a real band between them no matter what was
    asked for, and required mentally mirroring one direction's sweep to
    read the other's.
    fire_for()'s wrap-forward margin now accounts for the sense event
    being reported ~width_us/2 after its timestamp, not just a fixed lead
    ti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
    [webui.c]
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2026-09-24 Fix tracking-loop drift bug, add KICK control mode, and diagnostics
    control.c's schedule-slip check used to compare against exp_ns, an
    undisciplined accumulator that only ever advanced at the fixed nominal
    swing rate with no correction ever applied - so it drifted from real UTC
    forever at whatever rate the pendulum differs from nominal, eventually
    crossing the slip threshold on its own and forcing a "random" hold with
    no actual disturbance behind it. Removed exp_ns and its supporting code;
    the slip check now runs against the already-disciplined tracking NCO's
    own residual (rate_ns/rerr), which stays bounded under normal tracking.
    Add KICK, a second control-loop algorithm alongside the exist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
    [main.c]
2026-09-25 Working KICK-mode discipline loop, before AUTH/MEASURE/PTIMESCAN removal
    Last commit with the full AUTH (measured-authority credit-spend) path,
    CTRL_MEASURE, and PTIMESCAN sweep still present and working alongside
    KICK. KICK's feedback signal is now a fast EMA of ev->utc_ns -
    nominal_ns (a non-adapting NTP-anchored schedule), replacing the
    earlier slow rate_ns-based version that overshot; KICK is bidirectional
    and picks advance/retard itself from which threshold it crosses.
    FORCEERR was added to seed the error and exercise both directions on
    demand, and a live test today confirmed both directions of the
    hysteresis, plus that PTIME's placement value (not the software label)
    is what actually d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
    [webui.c]
2026-09-25 Remove AUTH/MEASURE/PTIMESCAN: KICK is now the only correction algorithm
    AUTH mode (spend phase error against a MEASURE'd ns-per-pulse price),
    CTRL_MEASURE and its least-squares authority-fit machinery, and the
    PTIMESCAN placement sweep built on top of it are gone. KICK's bang-bang
    hysteresis needs none of it, and today's live testing (FORCEERR-forced
    both directions, plus a placement swap that changed KICK's actual
    correction direction) confirmed KICK doesn't need to fall back to it.
    See bcd49bd for the last commit with that path intact if anything here
    turns out to still be wanted.
    Removed: credit_ns and the whole AUTH branch of track_event();
    cfg.control_mode and the AUTH/KICK dispatch i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
    [sense.c]
2026-09-25 Separate advance/retard pulse widths; 0 disables that direction
    fire_for() fired every corrective pulse at the same width regardless of
    direction (cfg.pulse_us), but the coil is already known to be wildly
    asymmetric - one placement retards far harder than the other advances
    (see the pulse_advance_us/pulse_retard_us comment in config.h) - so one
    width forced onto both is either too timid on the strong side or too
    hard on the weak one.
    PW now sets cfg.pulse_advance_width_us/pulse_retard_width_us together
    (advance_us retard_us, same order as PTIME); manual PULSE/PULSETRACE
    still fall back to cfg.pulse_us, unchanged. 0 in either PW slot
    deliberately disables that direction's corrections - fire_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
    [webui.c]
2026-09-25 web: line graph of uncorrected error vs swing, marked with KICK pulses
    Adds a ring buffer in control.c (errhist[], 1024 samples) recording
    sched_err_ns and whether/which direction KICK fired, once per tracked
    event. Exposed over /api/errhist?from=N, cursor-based like the existing
    /api/log console ring, so the page only asks for what's new each poll
    and builds up as long a client-side history as it wants (capped at
    1500 points) independent of the device's own ring size.
    The Loop card gets a new full-width "Uncorrected Error" section: a
    canvas line chart of the error trend with a fixed zero line, advance
    pulses marked in one color and retard in another, and a hover
    crosshair reporting swings-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
    [webui.c]
2026-09-25 web: NTP correction graph; reorder Loop/Clock/Time above both graphs
    Mirrors the uncorrected-error graph, one layer down: timebase.c gets a
    256-sample ring (tbhist[]) recording the offset of every NTP fix that
    was actually applied, and whether it was stepped outright rather than
    slewed in - pushed from tb_apply_fix()'s two real-correction return
    points. The very first fix is skipped; it anchors the model against
    nothing, so there's no correction size to report. Exposed over
    /api/ntphist?from=N, same cursor idiom as /api/errhist and /api/log.
    The page gets a matching "NTP Correction" graph next to "Uncorrected
    Error" - offset per fix as a line, stepped fixes marked - and both are
    now placed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
    [webui.c]
2026-09-25 Retire cfg.pulse_us; PULSE/PULSETRACE always require an explicit width
    Now that fire_for() reads pulse_advance_width_us/pulse_retard_width_us
    exclusively, cfg.pulse_us only ever fed a "0 means use this stored
    default" fallback for the two manual/diagnostic commands (PULSE,
    PULSETRACE) and the web's Test pulse button - a default nothing else
    needed. Dropped the fallback from all three: 0 now just refuses,
    consistent with how a disabled KICK direction already refuses rather
    than guessing. cfg.pulse_us itself is repurposed as inert padding
    (pad_pulse_us) rather than reshuffling the layout - no CONFIG_VERSION
    bump, so this flash doesn't cost another settings wipe.
    STATUS's drive section and the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
    [sense.c, webui.c]
2026-09-25 chime: show current face reading; remove the loop-correction feature
    Two related changes to the chime diagnostic, done together since both
    touch the same code:
    Add chime_face_now_sod() - what the hands should currently read, the
    last chime mark's offset applied to true local time right now. Same
    clock_sod chime_next() already computed for itself to find the next
    strike, now exposed on its own; chime_next() refactored to reuse it
    instead of duplicating the math. Shown as "clock face reads" in
    STATUS and a new Loop-card row on the web page.
    Remove CHIMEAPPLY, the web page's "Let the loop correct it" button,
    the OFFSET command, and the target_off/control_set_offset_ns()
    mechanism underneath b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
    [webui.c]
2026-09-25 chime: account for a strike that isn't exactly on the hour
    chime_next() assumed the striking train releases exactly on each
    interval boundary (clock_sod % interval == 0). A real movement can
    strike a few seconds either side of that - a fixed mechanical property
    of this specific clock, not something the discipline loop touches -
    which made the prediction wrong by that same fixed amount every time.
    New cfg.chime_strike_offset_s (signed seconds, default 0 = old
    behaviour): shifts which instant counts as "on the hour" before the
    modulus, so rel is 0 exactly when the hands are at a strike point. Set
    together with the existing interval/press-allowance via CHIMESET's new
    third argument, clamped to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
    [webui.c]
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

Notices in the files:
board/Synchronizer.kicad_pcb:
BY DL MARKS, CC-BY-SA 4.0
